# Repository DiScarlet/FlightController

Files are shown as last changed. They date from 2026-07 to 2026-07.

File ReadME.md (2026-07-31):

# Custom Flight Controller

A custom STM32F405-based flight controller designed from the ground up for modern FPV drones. Supports 4S–6S LiPo batteries, four ESC outputs with DShot, USB-C programming, and the ICM-42688-P IMU. The repository includes complete schematics, PCB design, CAD assembly, hardware documentation, and firmware flashing/bring-up guides. Designed for Betaflight compatibility with future ArduPilot support and additional onboard peripherals.

A preview of the complete assembly by Autodesk Viewer: https://autode.sk/4bVkogq

---

## Documentation

The repository contains additional documentation describing both the hardware and firmware aspects of the project.

Detailed information about the PCB architecture, power distribution, interfaces, mechanical design, manufacturing considerations, and future hardware revisions can be found in **`Docs/Hardware.md`**.

Firmware-related documentation, including programming interfaces, flashing instructions, hardware bring-up, Betaflight target information, and the planned firmware development roadmap, is available in **`Docs/Firmware.md`**.

---

## Repository Structure

FlightController/
├── CAD_Rendered/             # Fusion 360 assembly and mechanical models
├── FCHardware/               # KiCad project files
├── Devlogs/                  # The overall folder with devlog documents
│   ├── Images/                 # Figures and renders
│   └── Journal.md              # Development journal
├── Docs/                     #Documentation
│   ├── Hardware.md         
│   └── Firmware.md
├── ComponentsReferences.csv  # Component purchasing references (BOM)
├── FCHardware.csv            # Design references and documentation
└── README.md

---

## Gallery

### Schematic Overview

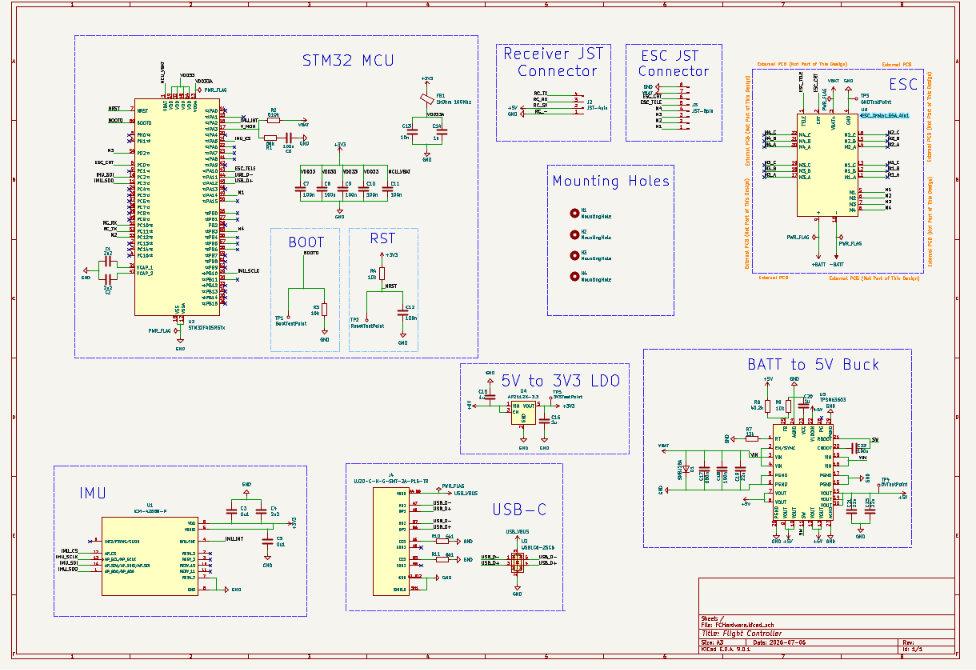
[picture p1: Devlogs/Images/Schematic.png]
Schematic


### PCB Layout (2D)

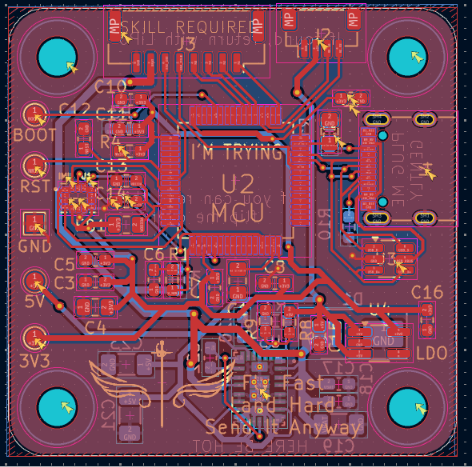
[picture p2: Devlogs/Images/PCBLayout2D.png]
PCB Layout


### PCB Front (3D)

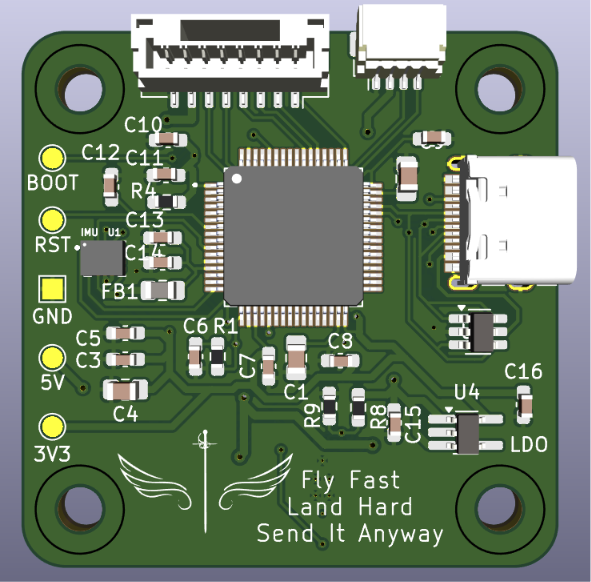
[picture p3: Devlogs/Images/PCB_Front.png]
PCB Front


### PCB Back (3D)

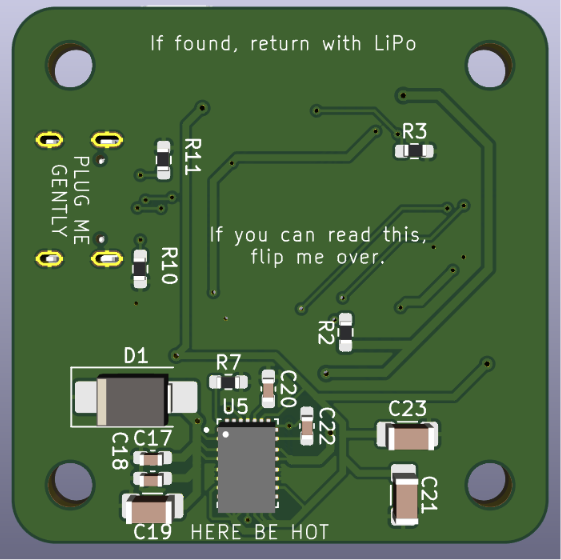
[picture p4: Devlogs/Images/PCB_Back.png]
PCB Back


### Fusion 360 Assembly

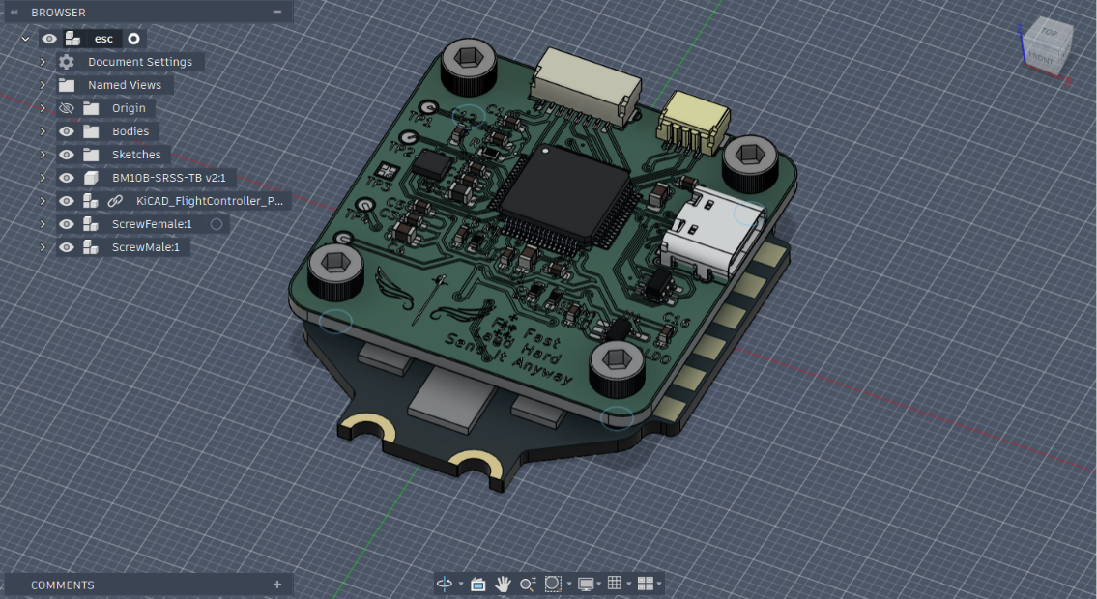
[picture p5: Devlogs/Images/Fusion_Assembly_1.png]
Fusion Assembly 1


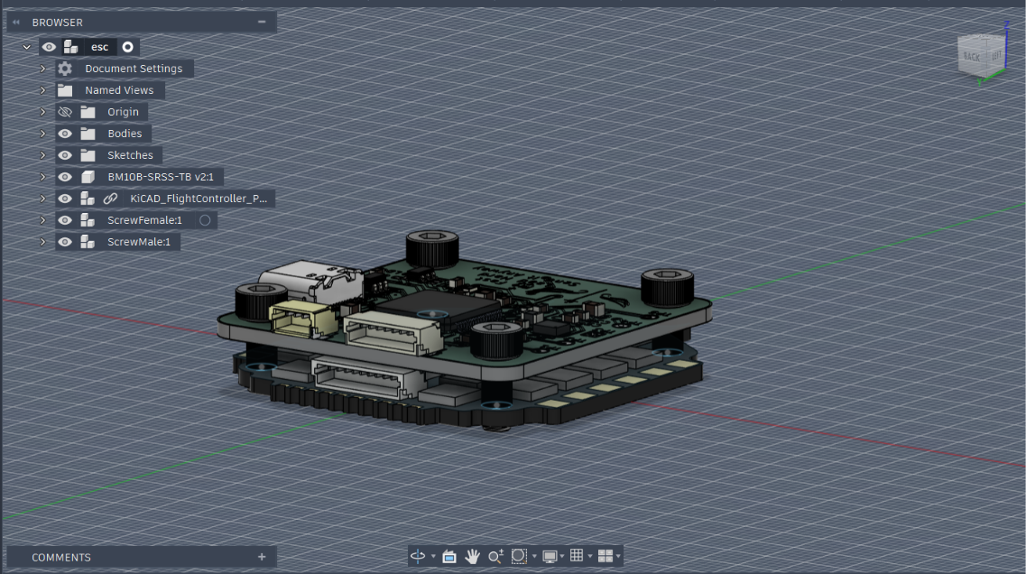
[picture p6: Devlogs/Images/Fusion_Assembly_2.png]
Fusion Assembly 2

---

## Acknowledgements

This project would not have been possible without the documentation, manuals, and resources provided by the engineering community. 

Special thanks to:
- STMicroelectronics, TDK InvenSense, Texas Instruments, Diodes Incorporated, Betaflight, Sahil Parashar for providing the generic ESC model that was adapted for this project, KiCad, Autodesk.
- **My family and friends** for their encouragement and support throughout the project.

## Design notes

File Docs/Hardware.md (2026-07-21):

# Hardware

This document describes the hardware design of the custom STM32F405-based flight controller developed throughout this project. The goal was to create a compact flight controller suitable for modern 4S–6S FPV drones while understanding every subsystem involved in the design process, from power regulation and sensor integration to PCB layout and mechanical compatibility.

The board follows the standard **30.5 × 30.5 mm mounting pattern**, allowing it to stack directly with compatible 4-in-1 ESCs such as the Hobbywing XRotor 65A used during development.

---

## Hardware Overview

The controller is built around the **STM32F405RGT6**, an ARM Cortex-M4 microcontroller widely used by the Betaflight ecosystem. Besides offering native USB support and sufficient processing power for modern flight control algorithms, choosing this MCU also makes future firmware development significantly easier due to the amount of existing documentation and community support.

Motion sensing is provided by the **ICM-42688-P** inertial measurement unit connected over SPI. Using SPI instead of I²C reduces communication latency and allows significantly higher update rates, which are essential for responsive flight control.

The board is powered directly from a **4S–6S LiPo battery**. Power conversion is performed in two stages. First, a TPSM63603 synchronous buck converter generates a regulated 5 V rail from the battery voltage. A dedicated AP2112K-3.3 low-dropout regulator then provides a clean 3.3 V supply for the microcontroller, IMU and other sensitive digital circuitry. Separating the switching regulator from the digital supply helps reduce switching noise reaching the sensors.

Battery voltage is measured using a resistor divider connected to one of the STM32 ADC inputs, while current consumption is obtained from the ESC's analog current output. These measurements allow the firmware to estimate battery state and power consumption during flight.

Communication with the ESC is performed using the DShot digital protocol, while ESC telemetry provides additional runtime information. An ExpressLRS receiver connects through UART, and additional communication interfaces have been reserved for future peripherals such as GPS, barometers or LiDAR modules.

Schematics

---

## PCB Design

The PCB was designed as a two-layer board with a continuous ground plane on both sides wherever possible. Particular attention was given to minimizing return current paths, placing decoupling capacitors close to their respective power pins and keeping high-speed SPI traces as short as practical.

USB differential pairs were routed together with matched topology, while power routing was prioritised before signal routing to ensure sufficient copper width on higher-current nets. Throughout the routing process I attempted to minimise unnecessary vias and avoided routing beneath sensitive analog circuitry whenever practical.

Rather than striving for the shortest possible traces everywhere, the layout prioritises predictable current flow, clean power distribution and component placement that follows each manufacturer's layout recommendations.

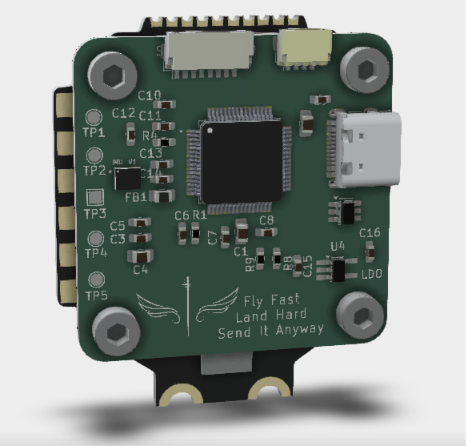
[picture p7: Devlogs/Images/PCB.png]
PCB


---

## Power Architecture

Power distribution is one of the most critical parts of the design. Since the board operates directly from a LiPo battery whose voltage changes significantly during discharge, careful regulation is required before powering the digital electronics.

The TPSM63603 generates the main 5 V rail from the battery input. This rail supplies external peripherals while also feeding the AP2112K regulator responsible for generating the clean 3.3 V supply used by the STM32, IMU and supporting circuitry.

Each power domain includes local decoupling capacitors positioned according to the manufacturers' recommendations. Ferrite bead filtering is also used to isolate particularly noise-sensitive sections of the circuit.

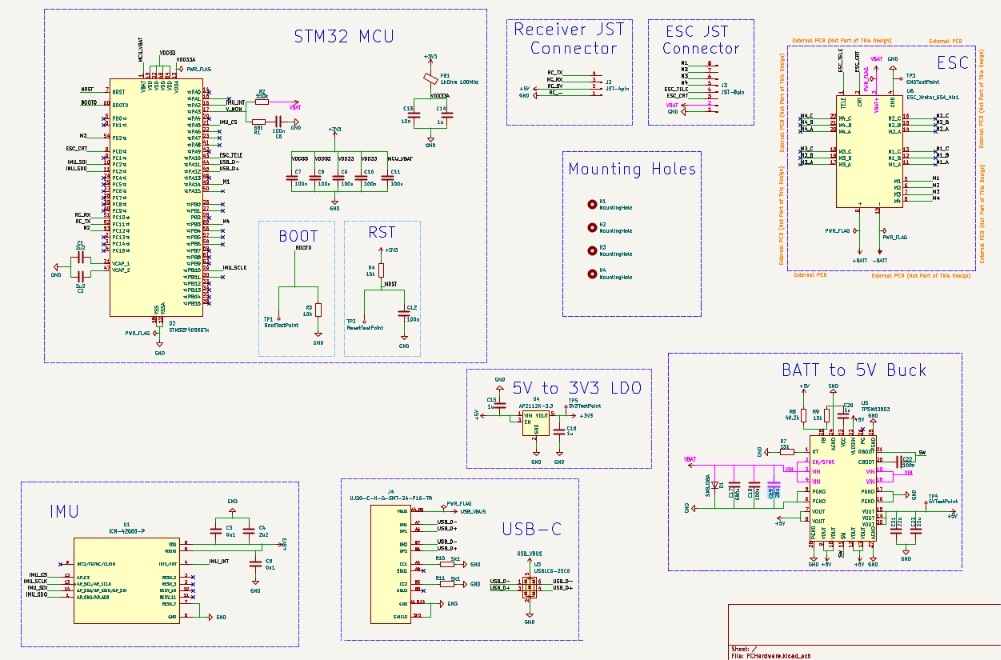
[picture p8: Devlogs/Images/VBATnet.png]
VBAT


---

## Microcontroller

The STM32F405 acts as the central controller for the entire system. It communicates with the IMU over SPI, receives radio commands through UART, generates DShot motor outputs and continuously monitors battery voltage and current through its ADC peripherals.

USB Full-Speed support allows firmware flashing and configuration without requiring an external programmer once the board has been brought up successfully.

During development, SWD remains the preferred programming interface because it provides full debugging capabilities and recovery if the firmware becomes corrupted.

PCB 3D

---

## IMU

Orientation of the ICM-42688-P follows the manufacturer's recommended reference frame to simplify firmware configuration. Special attention was given to local power decoupling and short SPI routing in order to reduce supply noise and communication latency.

The IMU communicates with the STM32 through dedicated SPI lines together with an interrupt line used for high-frequency sensor updates.

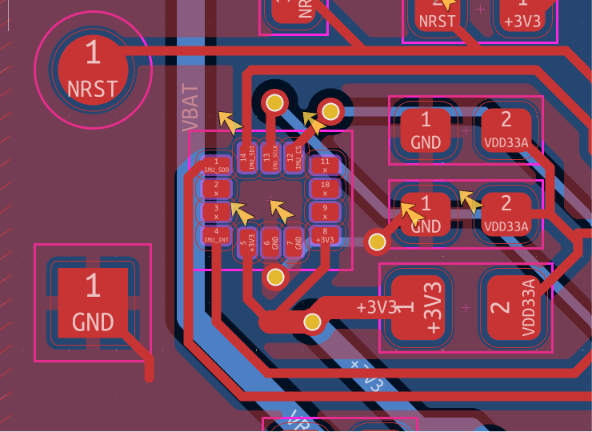
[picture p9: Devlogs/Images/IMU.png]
IMU


---

## External Interfaces

The board exposes several interfaces required by a modern flight controller.

A USB Type-C connector provides firmware flashing and configuration together with integrated ESD protection. Programming and debugging are additionally supported through dedicated SWD test pads.

Motor control is performed through DShot outputs connected to the ESC, while ESC telemetry and analog current sensing return runtime information back to the STM32.

An ExpressLRS receiver connects through UART, and additional interfaces remain available for future expansion.

---

## Test Points

Instead of dedicating valuable PCB space to buttons and programming headers, several functions are exposed through SMD test pads.

The board includes accessible test points for:

- 3.3 V
- 5 V
- Ground
- BOOT0
- NRST
- SWD programming

These pads simplify firmware flashing, debugging and hardware validation while keeping the PCB compact.

---

## Revision 2 Ideas

The most significant changes would include improving the routing around the buck converter, refining connector placement to simplify assembly, integrating more cleanly with the ESC stack, and exposing additional communication interfaces for peripherals such as GPS and LiDAR. Hardware validation of the first manufactured revision will ultimately determine which of these changes provide the greatest benefit.

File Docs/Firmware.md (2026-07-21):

# Firmware

The hardware has been designed primarily for Betaflight running on the STM32F405RGT6 microcontroller. Although the PCB has not yet been manufactured, the firmware workflow has already been planned to simplify the bring-up process once the first revision of the board arrives.

The STM32 provides two programming interfaces. During development I intend to use the SWD interface together with an ST-Link programmer, as it allows full debugging and recovery even if the firmware becomes corrupted. For normal firmware updates, the USB Type-C connector can be used through the STM32 built-in DFU bootloader.

---

## Programming Interfaces

The board exposes two independent programming methods.

### SWD

The SWD interface is available through dedicated test pads exposing:

- SWDIO
- SWCLK
- NRST
- 3.3 V
- GND

This interface will be used for the initial bring-up of the board, firmware development and debugging.

PCB 

---

### USB DFU

The STM32F405 contains a factory bootloader stored in ROM. By pulling **BOOT0** high during reset, the MCU enters Device Firmware Upgrade (DFU) mode and can be programmed directly over the USB Type-C connector without requiring an external programmer.

Both **BOOT0** and **NRST** are exposed as SMD test pads instead of push buttons in order to reduce PCB size.

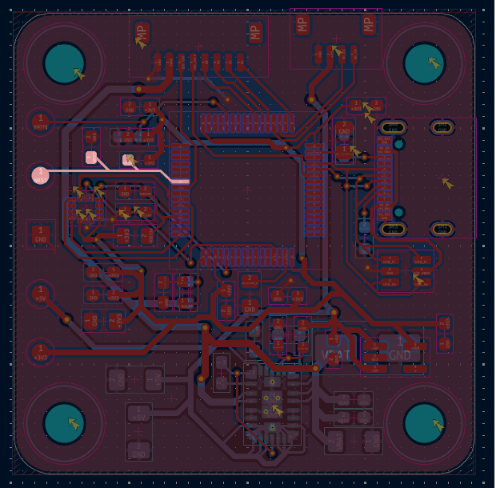
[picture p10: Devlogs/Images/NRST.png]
NRST


---

## First Power-Up

Once the PCB is assembled, the first goal is simply to verify that the hardware behaves as expected before any flight firmware is installed.

The planned validation sequence is:

1. Verify that there are no shorts on the power rails.
2. Apply power from a current-limited bench supply.
3. Confirm that the 5 V rail is generated correctly.
4. Verify the 3.3 V regulator output.
5. Ensure that the STM32 starts correctly.
6. Test USB enumeration.
7. Verify SWD communication.
8. Confirm SPI communication with the IMU.
9. Validate battery voltage and current sensing.

Only after these checks pass will Betaflight be flashed.

---

## Betaflight

The hardware was designed around the STM32F405 specifically because it is well supported by Betaflight.

Once the board has been electrically validated, the next milestone will be creating a custom Betaflight target describing the hardware configuration, including the IMU, motor outputs, UART assignments and ADC channels.

After the target is complete, the board should be configurable directly through Betaflight Configurator.

Link: https://betaflight.com/
Configurator: https://app.betaflight.com/

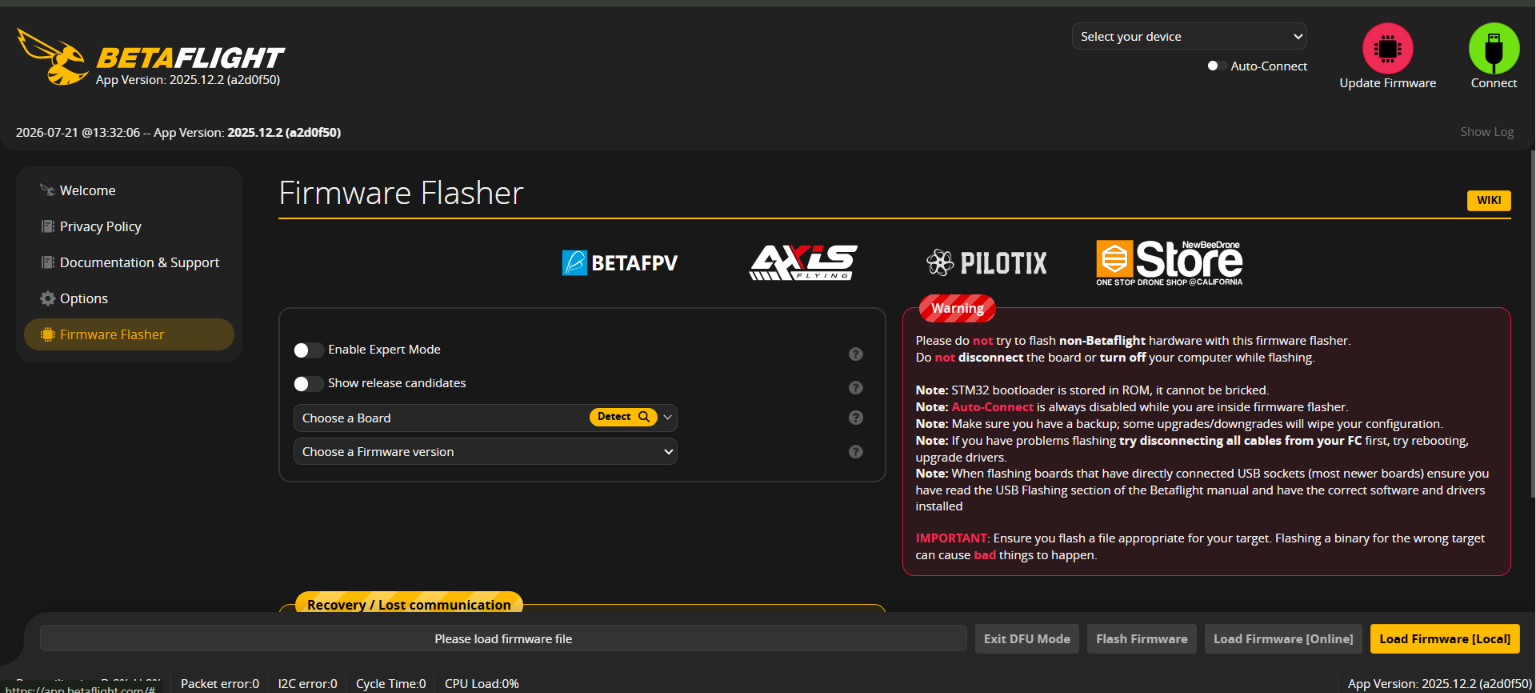
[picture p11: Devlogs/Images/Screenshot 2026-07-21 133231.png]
Betaflight


---

## Future Development

The first revision focuses entirely on reliable flight control hardware. Once basic functionality has been verified, future firmware development will expand to include additional peripherals such as GPS, LiDAR, barometer support and, eventually, ArduPilot compatibility.

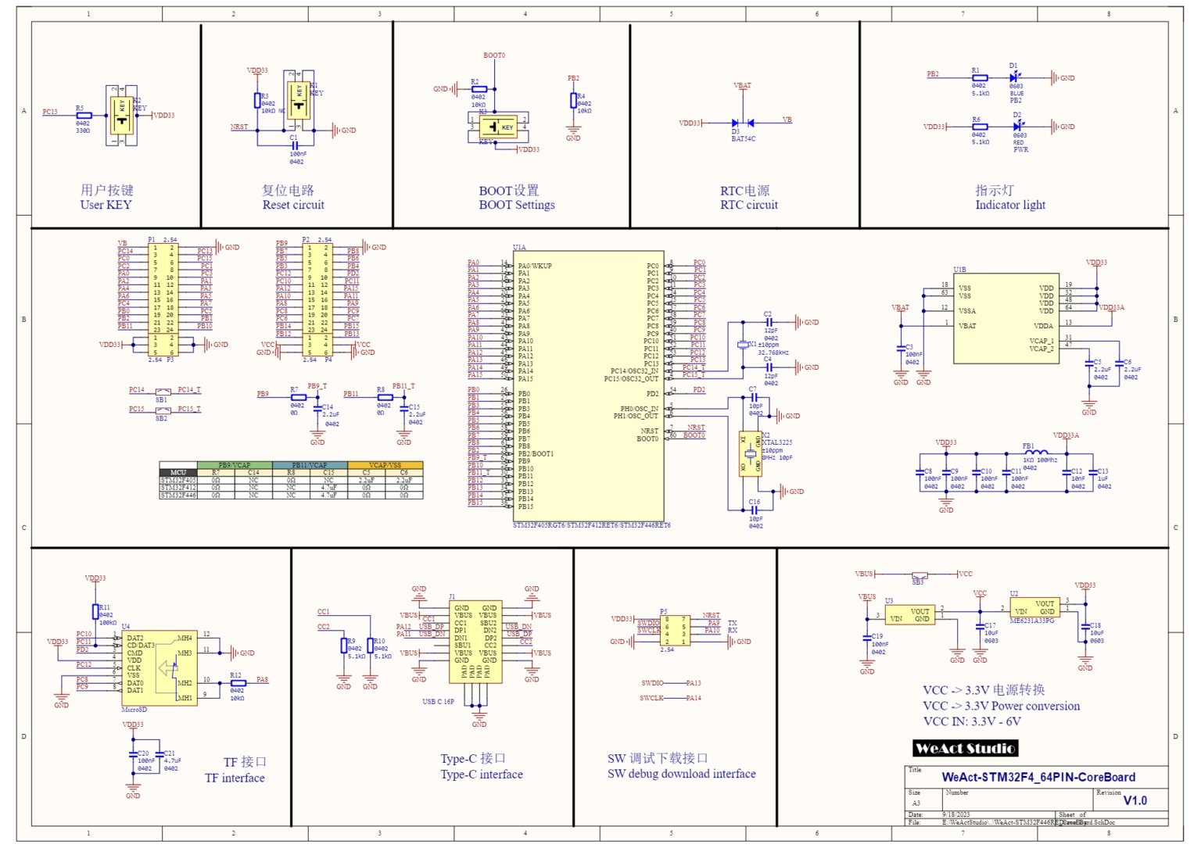
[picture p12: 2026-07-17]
FCHardware/Images/STM32F405-Development-Board-Schematic-1536x1085.jpg

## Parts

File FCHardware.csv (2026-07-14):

Reference | Value | Footprint | Datasheet | Qty | DNP | Exclude from BOM | Exclude from Board
C7,C12 | 1u | Capacitor_SMD:C_0603_1608Metric_Pad1.08x0.95mm_HandSolder | ~ | 2
C8,C11,C13,C22,C23,C25 | 100n | Capacitor_SMD:C_0603_1608Metric_Pad1.08x0.95mm_HandSolder | ~ | 6
C9 | 2n2 | Capacitor_SMD:C_0603_1608Metric_Pad1.08x0.95mm_HandSolder | ~ | 1
C10 | 680n | Capacitor_SMD:C_1210_3225Metric_Pad1.33x2.70mm_HandSolder | ~ | 1
C15,C16 | 22u | Capacitor_SMD:C_1206_3216Metric_Pad1.33x1.80mm_HandSolder | ~ | 2
C24 | 10u | Capacitor_SMD:C_0805_2012Metric_Pad1.18x1.45mm_HandSolder | ~ | 1
D1 | SMBJ28A | Diode_SMD:D_SMB_Handsoldering | ~ | 1
H1,H2,H3,H4 | MountingHole | MountingHole:MountingHole_3.2mm_M3 | ~ | 4 |  | Excluded from BOM
J1 | JST-8pin | Connector_JST:JST_GH_SM08B-GHS-TB_1x08-1MP_P1.25mm_Horizontal | ~ | 1
J3 | USB_C_Receptacle_USB2.0_16P |  | https://www.usb.org/sites/default/files/documents/usb_type-c.zip | 1
R7,R8 | 2k2 | Resistor_SMD:R_0603_1608Metric_Pad0.98x0.95mm_HandSolder | ~ | 2
R11 | 27.4k | Resistor_SMD:R_0603_1608Metric_Pad0.98x0.95mm_HandSolder | ~ | 1
R12 | 23.2k | Resistor_SMD:R_0603_1608Metric_Pad0.98x0.95mm_HandSolder | ~ | 1
R13,R24,R27 | 10k | Resistor_SMD:R_0603_1608Metric_Pad0.98x0.95mm_HandSolder | ~ | 3
R22 | 510k | Resistor_SMD:R_0603_1608Metric_Pad0.98x0.95mm_HandSolder | ~ | 1
R23 | 68k | Resistor_SMD:R_0603_1608Metric_Pad0.98x0.95mm_HandSolder | ~ | 1
R28,R29 | 5k1 +-5% | Resistor_SMD:R_0603_1608Metric_Pad0.98x0.95mm_HandSolder | ~ | 2
SW3 | SW_Push |  | ~ | 1
TP2 | GNDTestPoint |  | ~ | 1
TP3 | 3V3TestPoint |  | ~ | 1
TP5 | ENTestPoint |  | ~ | 1
U2 | MPU-6050 | Sensor_Motion:InvenSense_QFN-24_4x4mm_P0.5mm | https://invensense.tdk.com/wp-content/uploads/2015/02/MPU-6000-Datasheet1.pdf | 1
U4 | TPSM63603 | TPSM63603EXTRDHR | https://www.ti.com/lit/ds/symlink/tpsm63603.pdf | 1
U5 | ESC_Xrotor_65A_4in1 |  | https://www.hobbywing.com/en/uploads/file/20250324/715cf619a357b18a11761e3bb13e4f6d.pdf | 1
U8 | ESP32-S3-MINI-1U | RF_Module:ESP32-S2-MINI-1U | https://www.espressif.com/sites/default/files/documentation/esp32-s3-mini-1_mini-1u_datasheet_en.pdf | 1
U9 | USBLC6-2SC6 | Package_TO_SOT_SMD:SOT-23-6 | https://www.st.com/resource/en/datasheet/usblc6-2.pdf | 1

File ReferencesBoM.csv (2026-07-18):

Reference | Value | Store Name | Link
C1,C2,C4 | 2u2 | 0805YC225JAT2A | https://www.mouser.fi/en/ProductDetail/KYOCERA-AVX/0805YC225JAT2A?qs=%252BdQmOuGyFcHAs%2FdSKfbQcg%3D%3D
C3,C5 | 0u1 | 0603YA102FAT2A | https://www.mouser.fi/en/ProductDetail/KYOCERA-AVX/0603YA102FAT2A?qs=Q0wCMCRSJ1vE1Ym6h4QWAA%3D%3D
C13 | 10n | KAF15AR72A103JM | https://www.mouser.fi/en/ProductDetail/KYOCERA-AVX/KAF15AR72A103JM?qs=Jm2GQyTW%2FbiSEofrKTFSYg%3D%3D
C14,C20,C15,C16 | 1u | KGM15BR71C105JT | https://www.mouser.fi/en/ProductDetail/KYOCERA-AVX/KGM15BR71C105JT?qs=Z%252BL2brAPG1K2MbrAaZa7Nw%3D%3D
C7,C8,C9,C10,C11,C12,C6,C18,C22 | 100n | KGF15AR71H104JT | https://www.mouser.fi/en/ProductDetail/KYOCERA-AVX/KGF15AR71H104JT
C9 | 2n2 | KAF15AR71H222KT | https://www.mouser.fi/en/ProductDetail/KYOCERA-AVX/KAF15AR71H222KT?qs=OcgtsXO%252B3gvSeuEwjFHfGw%3D%3D
C10 | 680n | 06035C682MAT2A | https://www.mouser.fi/en/ProductDetail/KYOCERA-AVX/06035C682MAT2A
C19,C21,C23 | 22u | C3216X5R1V226M160AC | https://www.mouser.fi/en/ProductDetail/TDK/C3216X5R1V226M160AC?qs=NRhsANhppD8TwN31eZ1xGQ%3D%3D
C24 | 10u | MCASL21GBB7106KTNA01 | https://www.mouser.fi/en/ProductDetail/TAIYO-YUDEN/MCASL21GBB7106KTNA01
D1 | SMBJ28A | SMBJ28A | https://www.mouser.fi/en/ProductDetail/Taiwan-Semiconductor/SMBJ28A?qs=tHU%2FlV7kTyQeXZsIvFkTlA%3D%3D
FB1 | 1kOhm 100Mhz | ABPY00201209102Y00 | https://www.mouser.fi/en/ProductDetail/Pulse-Electronics/ABPY00201209102Y00?qs=DRkmTr78QAQV9rs2r0z4%2Fg%3D%3D
H1,H2,H3,H4 | MountingHole | M3 kuusiokoloruuvi 18mm | https://kauppa.sintosen.com/product/1973/m3-kuusiokoloruuvi-a2-70-teras-10kplpss-iso7380
J1 | JST-8pin | Cable JST GH 1 | 25mm 8pin 150 mm | https://kauppa.sintosen.com/product/3806/jst-gh-125-liitin-naaras-johdolla
J1 | JST-8pin-Connector | 502386-0870 | https://www.mouser.fi/en/ProductDetail/Molex/502386-0870?qs=Fn3VdHBzkclKyntjDrqNyw%3D%3D
J2 | JST-4pin
J3 | USB_C_Receptacle_USB2.0_16P | UJ20-C-H-G-SMT-2A-P16-TR | https://www.mouser.fi/en/ProductDetail/Same-Sky/UJ20-C-H-G-SMT-2A-P16-TR?qs=6avfeC6zeS4lRZlgHZHlwQ%3D%3D
R7,R8 | 2k2 | RN73R1JTTD2201B50 | https://www.mouser.fi/en/ProductDetail/KOA-Speer/RN73R1JTTD2201B50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
R11 | 27.4k | RC0603FR-0727K4L | https://www.mouser.fi/en/ProductDetail/YAGEO/RC0603FR-0727K4L?qs=diQw95jMAeON0J0BtxrSNg%3D%3D
R12 | 23.2k | RC0603FR-0723K2L | https://www.mouser.fi/en/ProductDetail/YAGEO/RC0603FR-0723K2L?qs=diQw95jMAePwAyVFAaRAcQ%3D%3D
R13,R24,R27 | 10k | RC0603FR-0710KL | https://www.mouser.fi/en/ProductDetail/YAGEO/RC0603FR-0710KL?qs=grNVn54RoB%252B3GtjbJj3wJQ%3D%3D
R2 | 510k | RC0603FR-07510KL | https://www.mouser.fi/en/ProductDetail/YAGEO/RC0603FR-07510KL?qs=gt6vzsuosg24q32x%252BBO%252BsA%3D%3D
R7 | 13k | ERA-3ARW133V | https://www.mouser.fi/en/ProductDetail/Panasonic/ERA-3ARW133V
R8 | 40.2k | TNPW060340K2BETA | https://www.mouser.fi/en/ProductDetail/Vishay/TNPW060340K2BETA
R1 | 68k | RC0603FR-1368KL | https://www.mouser.fi/en/ProductDetail/YAGEO/RC0603FR-1368KL?qs=IuGqVx9wL0JGAH4a3IMPOw%3D%3D
R28,R29 | 5k1 | RC0603FR-075K1L | https://www.mouser.fi/en/ProductDetail/YAGEO/RC0603FR-075K1L?qs=gt6vzsuosg2jUUwxnI2PJQ%3D%3D
U1 | ICM-42688-P | ICM-42688-P | https://www.mouser.fi/en/ProductDetail/TDK-InvenSense/ICM-42688-P?qs=OlC7AqGiEDk8QrNAV728zw%3D%3D
U2 | STM32F405RGTx | STM32F405RGT6 | https://www.mouser.fi/en/ProductDetail/STMicroelectronics/STM32F405RGT6?qs=Z8%252BeY1k3TIKgj7QWsYGpQw%3D%3D
U3 | USBLC6-2SC6 | USBLC6-2SC6 | https://www.mouser.fi/en/ProductDetail/STMicroelectronics/USBLC6-2SC6?qs=po45yt2pPpu%2FhNIlwQdTlg%3D%3D
U4 | AP2112K-3.3 | AP2112K-3.3TRG1 | https://www.mouser.fi/en/ProductDetail/Diodes-Incorporated/AP2112K-3.3TRG1?qs=x6A8l6qLYDDPYHosCdzh%2FA%3D%3D
U5 | TPSM63603 | TPSM63603SRDHR | https://www.mouser.fi/en/ProductDetail/Texas-Instruments/TPSM63603SRDHR?qs=tlsG%2FOw5FFhaJm%252BTRcoafA%3D%3D
ESC/U6 | ESC_Xrotor_65A_4in1 | Hobbywing XRotor 65A FPV 4in1 ESC 30902064 | https://hobbyfactory.fi/et/p87240/hobbywing-xrotor-65a-fpv-4in1-esc-30902064
RECEIVER.Radiomaster XR1 Nano Multi-Frequency ExpressLRS Receiver EU-LBT | https://originhobbies.com/shop/radio-control/radio-receivers/elrs-protocol/radiomaster-xr1-nano-multi-frequency-expresslrs-receiver-eu-lbt/

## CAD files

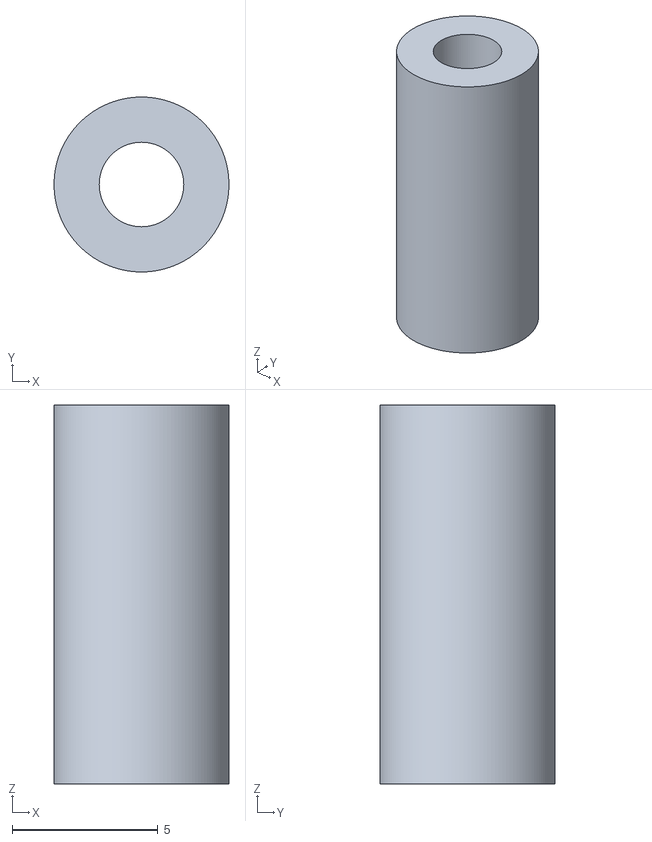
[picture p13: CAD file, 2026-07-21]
CAD_Rendered/Components/Screw/13mm.stl
6.00 x 6.00 x 13.0

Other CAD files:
CAD_Rendered/FC_ESC_Assembly.step
CAD_Rendered/Components/KiCAD_FlightController_PCB.step
FCHardware/KiCAD_Libs/FC3DModels/JST_SH_SM08B-SRSS-TB_1x08-1MP_P1.00mm_Horizontal.step
FCHardware/KiCAD_Libs/FC3DModels/ICM-42688-P.step
FCHardware/KiCAD_Libs/FC3DModels/TPSM63603EXTRDHR.step
FCHardware/KiCAD_Libs/FC3DModels/STM32F405RGT6.STEP
FCHardware/KiCAD_Libs/FC3DModels/UJ20-C-H-G-SMT-2A-P16-TR.step
FCHardware/KiCAD_Libs/FC3DModels/PRT-14417--3DModel-STEP-1.STEP
CAD_Rendered/Components/Screw/CHC M3 L8.step
CAD_Rendered/FC_ESC_Assembly.3mf

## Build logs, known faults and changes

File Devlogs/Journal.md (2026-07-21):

title: "Flight Controller"
author: "Diana"
description: "Design and development of a custom STM32F405-based flight controller for Betaflight-compatible FPV drones"
created_at: "2026-07-06"

----------------------
## Project Journal

### Day 1
created_at: "2026-07-06"

Lapse Links: 
- [Lapse Schematics 1](https://lapse.hackclub.com/timelapse/7EcZ5cB8u3wI)
- [Lapse Schematics 2](https://lapse.hackclub.com/timelapse/V2QrQ_YrS28b)
Day 1: I am really excited to start this amazing project! 
I'll put a lot of work into this. I looked up some tutorials already, but a lot of them are too old and don't use modern technology or they use components I'd prefer not to.I want to start by following the schematics in the tutorial, and then, once I understand the full idea, switch to a completely different version created entirely by me.
I added the initial component schematics with the ESP32 WROOM Module. I might change it later, but it is currently missing a lot of components, so the tutorial has to add them and wire them up. This will help me better understand the internal structure of the ESP32 WROOM module. Even if I switch to more modern microcontrollers later, it will still help me progress faster because I will understand the internal wiring.
So, here is the basic structure of all the components that I've added and wired:
1) Microcontroller: I decided to go with the ESP32 WROOM 32.
2) CP2104: For USB-to-UART communication.
3) Flashing Sequence: For automatic firmware updates.
4) USB-B / USB-C: I will decide on one later. 
5) Motor Connectors: For connecting to the motors.
6) H-Bridge Circuit: For controlling the motors.
7) 3V3 Voltage Regulator: For stabilizing the input voltage to the ESP32.
8) Battery Charger: To prevent damage to the battery.
9) Accelerometer (MPU6050): This also contains a gyroscope, a temperature sensor, and a Digital Motion Processor that act as sensors for the controller's brain.
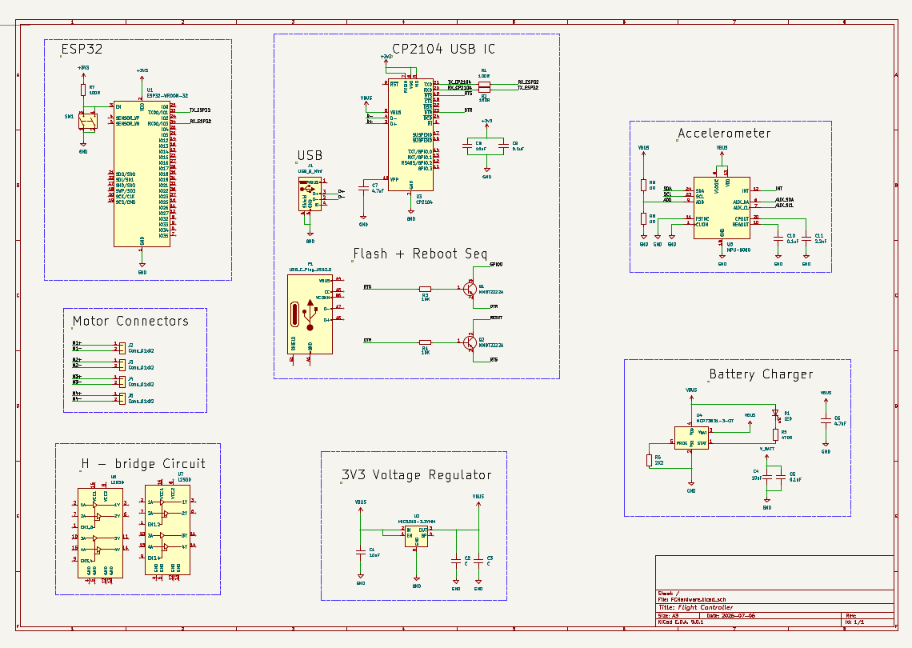
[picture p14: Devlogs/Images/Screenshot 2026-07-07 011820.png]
Schematics Day 1

This is going to be an epic project, and I am really excited to begin. I am still not sure if this is the right controller to choose, but many tutorials suggest it, so who am I to go against them?
I like what I've done so far. Even though I am still not finished, I understand way more now by looking at tutorials and doing my own thing. I'll try to optimize it tomorrow.

---------------------
created_at: "2026-07-07"

Lapse Links: 
- [Lapse Schematics 3](https://lapse.hackclub.com/timelapse/JKiI6UassHQw)
### Day 2
Even though I really enjoyed the progress of working on a lot of interesting stuff yesterday, there were too many unnecessary components. I changed the main controller to the Adafruit ESP32 Feather V2, which reduced the amount of components drastically.
This board has a lot of components already integrated into its internal structure, so I could alter the following elements:
1) Microcontroller: Adafruit ESP32 Feather V2. Why V2? It has USB-C and easier power management already integrated.
2) Removed CP2104: Already integrated into item 1. 
3) Removed Flashing Sequence: Already integrated into item 1.
4) Removed USB-B / USB-C: Already integrated into item 1.
5) H-Bridge Circuit: Upgraded to more modern DRV8833PWP drivers.
6) Removed 3V3 Voltage Regulator: Already integrated into item 1. 
7) Removed Battery Charger: Already integrated into item 1. 

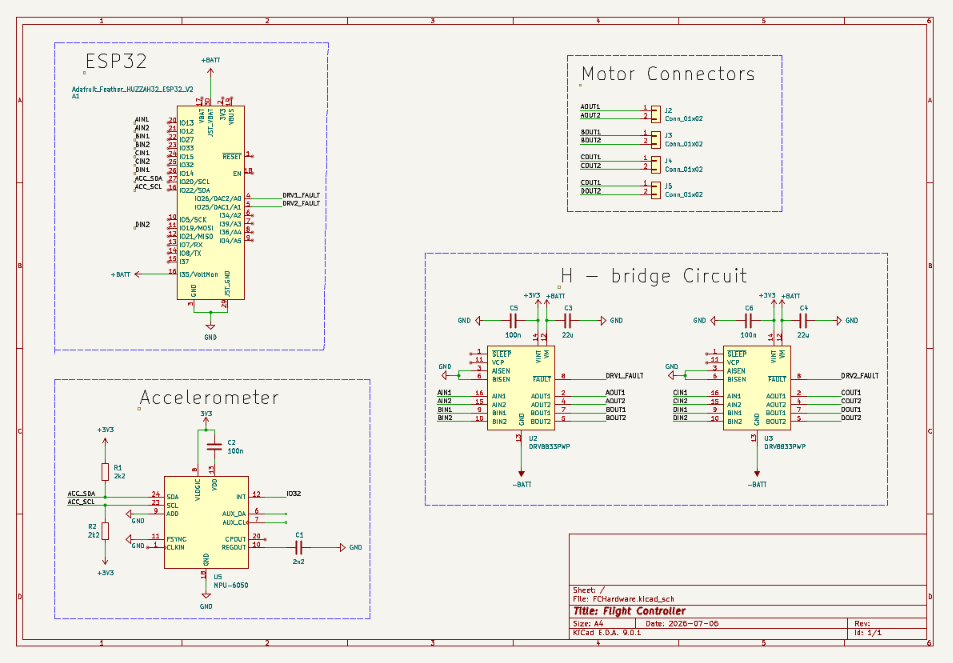
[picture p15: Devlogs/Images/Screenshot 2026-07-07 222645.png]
Schematics Day 2

Overall, the schematics look way more readable now, and the component switch was well worth the trouble. It did not take me that long, but it will definitely make assembly way easier.

--------------------
created_at: "2026-07-08"
Lapse Links: 
- [Lapse Schematics 4](https://lapse.hackclub.com/timelapse/zhmaA2kOq_Py)
### Day 3
To use more powerful motors, my infrastructure allows me to switch from a 1S to a 2S LiPo battery. This is mainly due to the DRV8833PWP drivers, which accept 2.7V to 10.8V — a span that falls right into the 2S range. To make this work, I chose the TPS62125DSG step-down regulator. I was wondering how to connect the battery to the PCB itself and settled on the Amass XT60PW male PCB-mount connector. Most JST connectors are too weak, and an XT90 is overkill. I ended up a bit confused by all the different power inputs and outputs, but I eventually figured out the wiring and ended up with the following schematic:
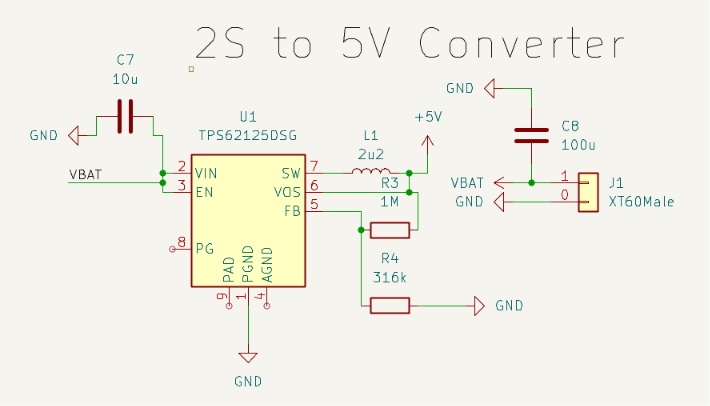
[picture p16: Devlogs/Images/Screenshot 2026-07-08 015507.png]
TPS62125DSG Wiring

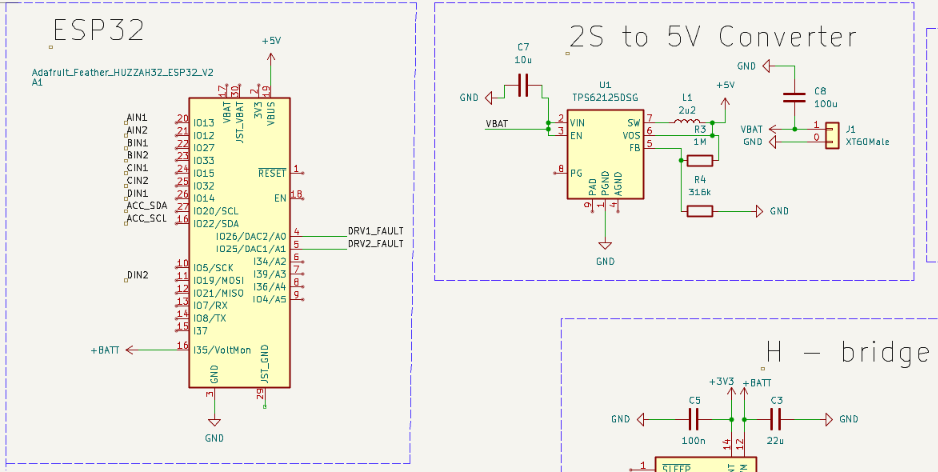
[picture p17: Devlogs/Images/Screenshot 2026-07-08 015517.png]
ESP32 + Power Schematics


--------------------
created_at: "2026-07-11"
Lapse Links: 
- [Lapse Schematics 5](https://lapse.hackclub.com/timelapse/zi6OlWzVVC0I)
### Day 4
Today I made significant modifications to the flight controller design. I stepped up from a simple 2S brushed drone concept to the prototype architecture of a real 4S 7" brushless drone.

1. Updated the buck converter

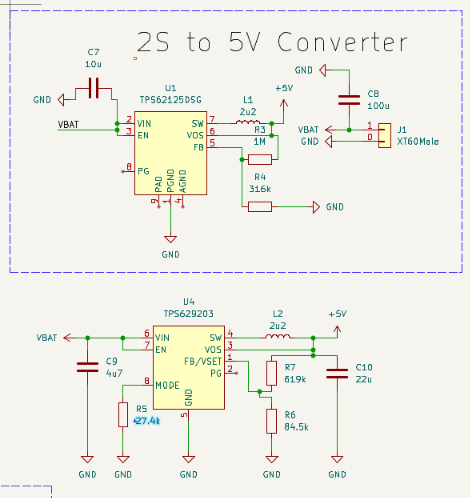
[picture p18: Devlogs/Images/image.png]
TPS629203
I replaced the TPS62125 with the newer TPS629203, which supports my new power requirements and offers better efficiency. 

2. Switched from brushed to brushless architecture

Initially, I considered replacing the DRV8833PWP because it is obsolete with the DRV8847PWPR. However, since I had to redesign the motor-driving stage anyway, I decided it made more sense to switch to brushless motors and use a dedicated 4-in-1 ESC instead of H-bridges.

Because the TPS629203 supports a 4S LiPo, I also upgraded the battery from 2S to 4S. This removed the need for additional power circuitry changes and resulted in a much cleaner flight controller schematic.

3. Selected the propulsion system

To avoid designing around unknown components, I chose the motors first and built the rest of the system around them.

Motor: Hobbywing XRotor 2807 1300KV

Product:
https://hobbywinguav.com/product/2807/

Datasheet:
https://www.hobbywing.com/uploads/file/20250207/46cccf132a1b9971633a272da27fb76f.pdf

4. Selected the ESC

Since I switched to brushless motors, I removed the H-bridge motor drivers and replaced them with a 4-in-1 ESC.

After comparing several candidates and checking compatibility with the selected motors, I chose the:

Hobbywing XRotor 65A 4-in-1 Lite BLS V2 ESC

Datasheet:
https://www.hobbywing.com/en/uploads/file/20251120/81969c41227e3db78d441e9c20476cf1.pdf

Product:
https://www.drone-fpv-racer.com/en/hobbywing-65a-4in1-6s-lite-bls-v2-fpv-esc-15678.html
[BLS Version](<Images/Screenshot 2026-07-11 032116.png>)

5. Updated motor connections

I initially changed the motor connectors to 3-pin connectors for brushless motors.

Later, I realised that since the motors connect directly to the ESC, the flight controller PCB does not need motor connectors. Therefore, I removed them from the schematic.

6. Added battery monitoring

I added:

Battery voltage monitoring using a resistor divider connected to an ESP32 ADC pin.
Battery current monitoring using the ESC's analog current output connected to another ESP32 ADC pin.
ESC telemetry connected to a UART RX pin on the ESP32.

7. Updated the power architecture

The battery is now connected directly to the ESC through an XT60 connector.

I also added:

a 680 µF bulk capacitor (provided with the ESC),
a TVS diode across VBAT and GND for transient protection.

TODO:
- Replace the ESP32 Feather development board with a custom ESP32 circuit in the final design.
- Verify the ESC telemetry connector (SH1.0) and determine the best way to interface it with my PCB.
- Verify that the ESC current output is 3.3 V compatible before connecting it directly to the ESP32 ADC.
- Run KiCad ERC and begin PCB layout.

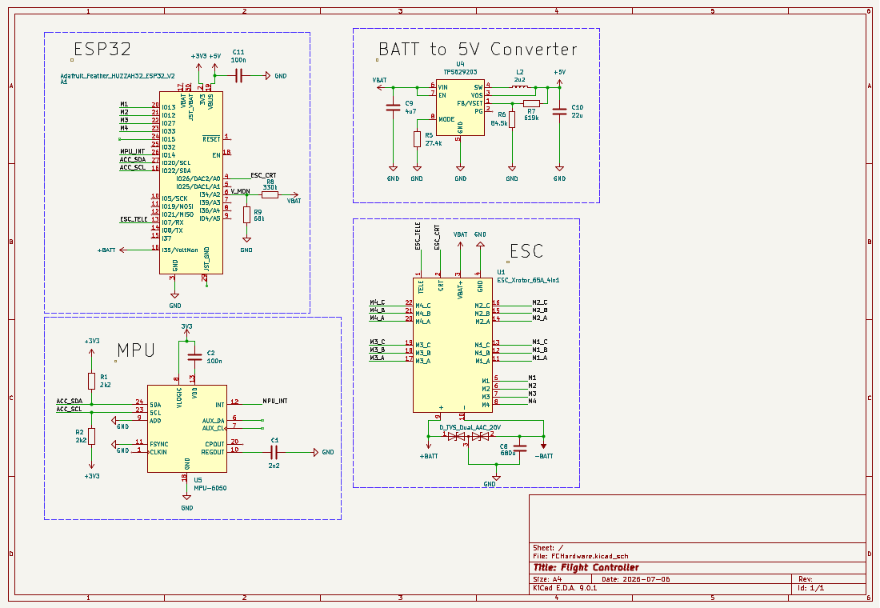
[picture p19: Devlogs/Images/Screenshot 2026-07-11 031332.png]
Full Shcematics of Today


--------------------
created_at: "2026-07-12"
Lapse Links: 
- [Lapse Schematics 6](https://lapse.hackclub.com/timelapse/6Uwn8jtsZGfW)
- [Lapse Schematics 7](https://lapse.hackclub.com/timelapse/CSfY-yu12VB2)
- [Lapse Schematics 8](https://lapse.hackclub.com/timelapse/6Uwn8jtsZGfW)
- [Lapse Schematics 9](https://lapse.hackclub.com/timelapse/6Uwn8jtsZGfW)
### Day 5
Today I replaced the ESP32 Feather V2 development board with the actual ESP32-S3-WROOM-1U module and all of the supporting circuitry required for a production PCB. The Feather dev board served me well for prototyping, but it was time to move to a real hardware design.
ESP32
- Removed the Adafruit ESP32 Feather V2 development board.
- Switched to the ESP32-S3-WROOM-1U module.
- Added the required support circuitry:
  - EN reset circuit
  - BOOT button
  - USB-C connector
  - USB D+ / D− wiring
  - Decoupling capacitors
  - Voltage divider for battery monitoring

ESP32-S3-WROOM-1U datasheet:
https://documentation.espressif.com/esp32-s3-wroom-1_wroom-1u_datasheet_en.pdf
Originally the design targeted a 4S battery:

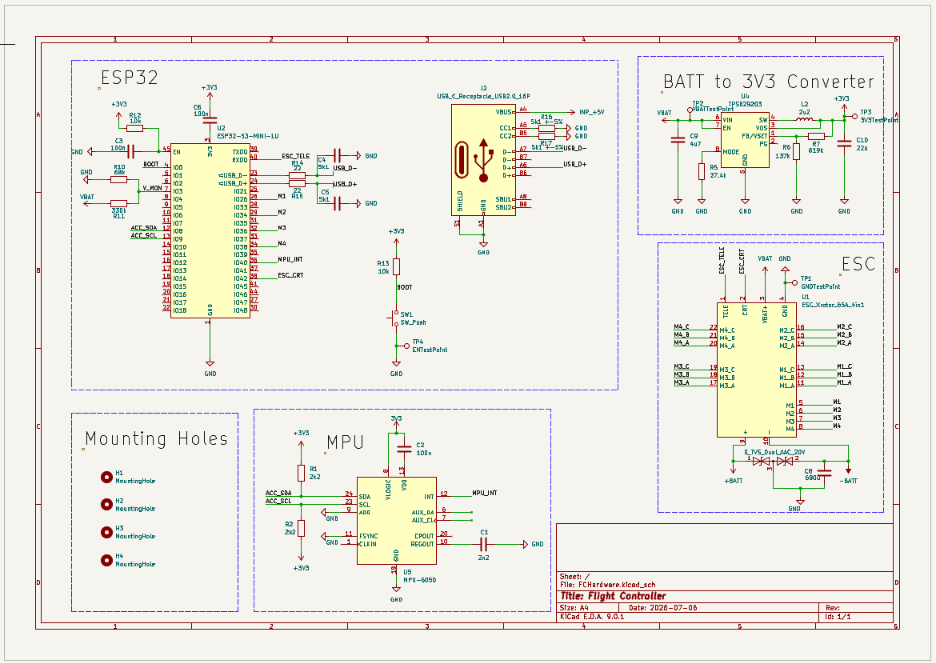
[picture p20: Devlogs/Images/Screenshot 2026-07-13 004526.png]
4S Architecture


I added:
- test points for debugging,
- PCB mounting holes,
- improved power distribution.

I then decided to redesign the power supply so the flight controller can support both **4S and 6S LiPo batteries**.

The previous TPS629203 regulator was replaced with the **TPSM63603**, which supports input voltages up to 36 V.

TPSM63603 datasheet:
https://www.ti.com/lit/ds/symlink/tpsm63603.pdf

I created a custom KiCad symbol for the TPSM63603:

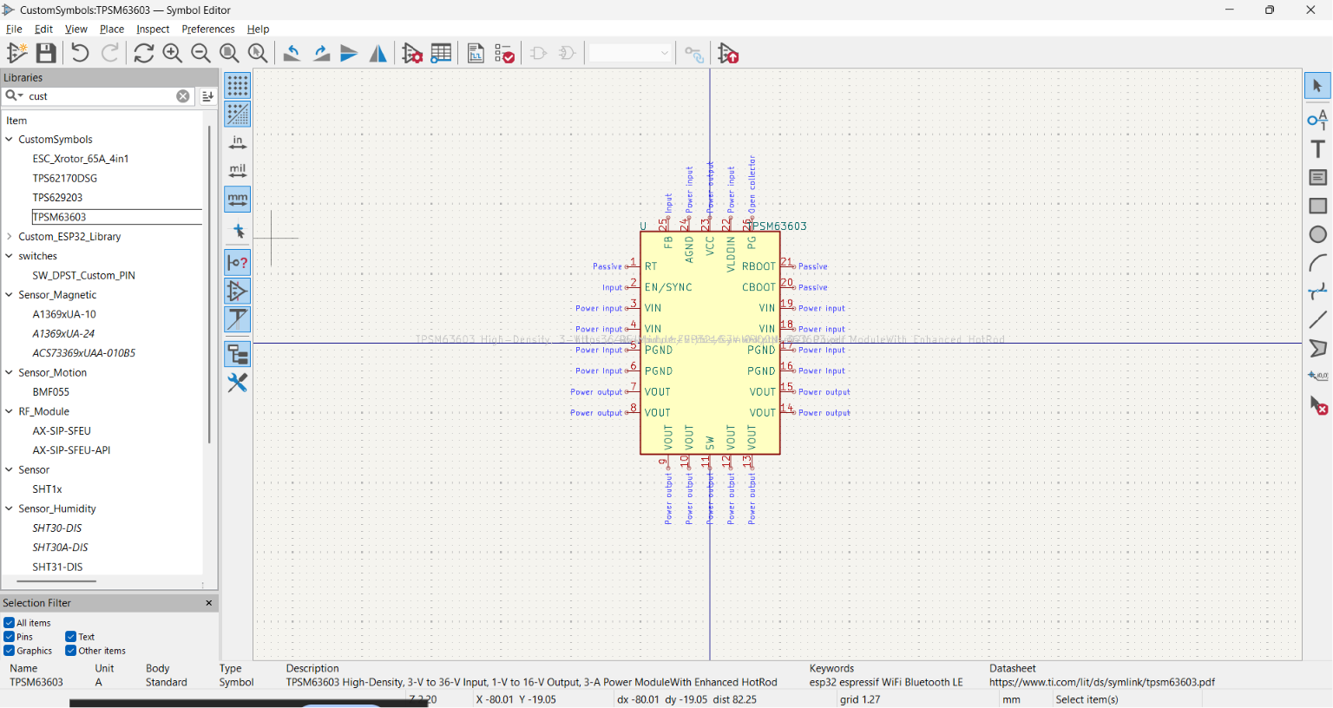
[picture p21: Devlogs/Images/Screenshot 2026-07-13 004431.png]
TPSM63603 Symbol


Then I integrated and wired the new regulator into the schematic:

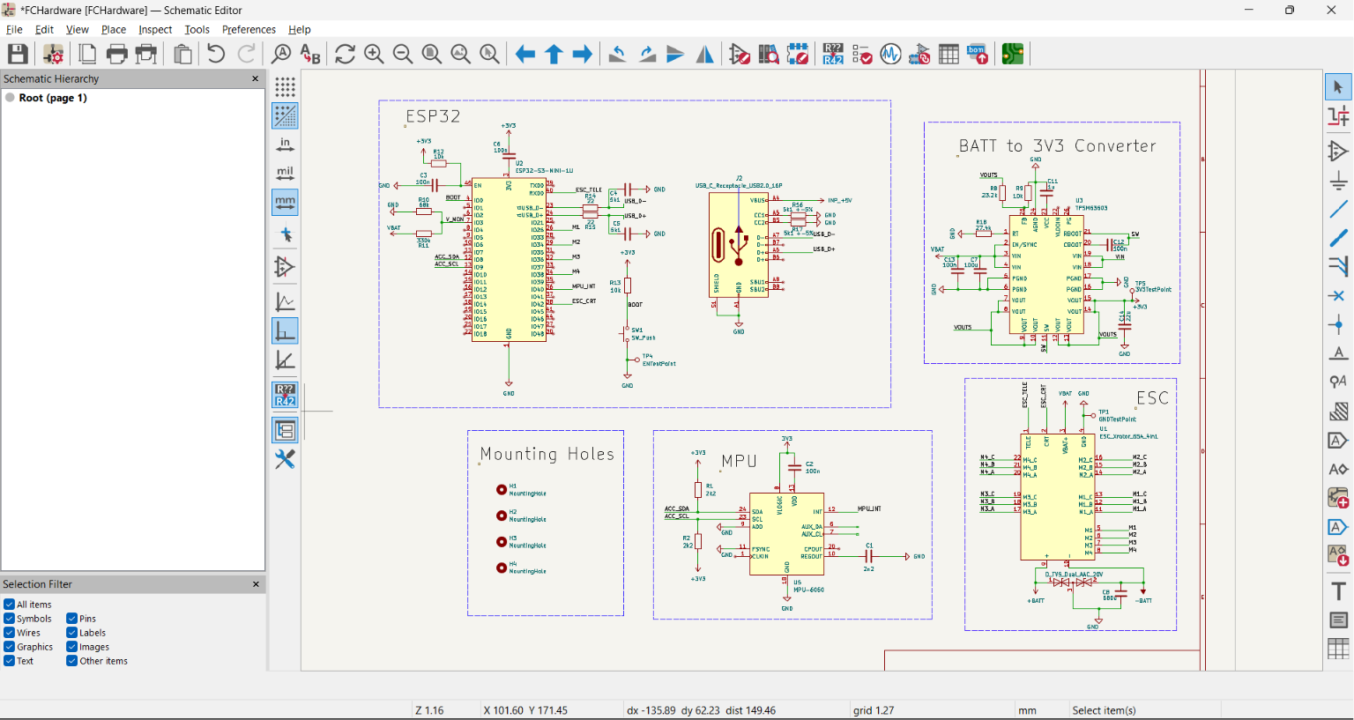
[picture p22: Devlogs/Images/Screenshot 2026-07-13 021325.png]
4S-6S Architecture Start


After my laptop crashed, I noticed the screen recorder froze for the last ~10 minutes and only recorded a still image. I added a screenshot of the completed work as proof of progress.

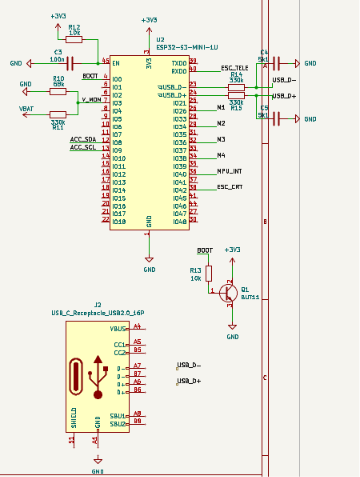
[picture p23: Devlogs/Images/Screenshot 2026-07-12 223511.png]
USB C


## TODO:
- Verify the TPSM63603 wiring against the TI reference schematic.
- Check all capacitor values and voltage ratings.
- Verify the feedback resistor values for a 3.3 V output.
- Add a capacitor on the battery voltage monitoring line (V_MON).
- Run ERC before starting PCB layout.
- Begin PCB component placement.
- Go touch the grass and finally sleep.

--------------------
created_at: "2026-07-13"
Lapse Links:
- [Lapse Schematics 10](https://lapse.hackclub.com/timelapse/1pxt6WZpChBw)
- [Lapse Schematics 11](https://lapse.hackclub.com/timelapse/10gVjKCt_ep9)
- [Flight Controller Footprints 1](https://lapse.hackclub.com/timelapse/hQegLY-AzRu6)
- [Flight Controller Footprints 2](https://lapse.hackclub.com/timelapse/EoTzfVyzHLk1)

### Day 6
Continued refining the flight controller schematic and completed the transition to support a **4S–6S LiPo** power input. I replaced the original 20 V TVS diode with a **Vishay SMBJ28A**, which has a 28 V reverse working voltage, making it suitable for a fully charged 6S LiPo (25.2 V) while still providing transient protection.

While reviewing the schematic, I discovered a short circuit by using KiCad's **Net Highlight** tool. Highlighting the **3.3 V** net also highlighted **GND**, immediately indicating a direct short. After tracing the connection, I found that the ESP32's 3.3 V decoupling capacitors had been wired incorrectly. Fixing the capacitor connections removed the short.

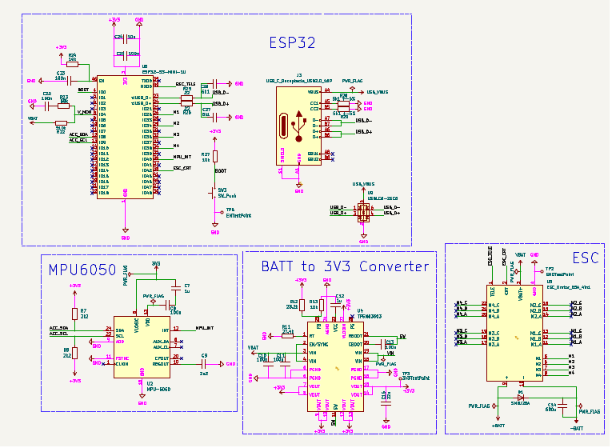
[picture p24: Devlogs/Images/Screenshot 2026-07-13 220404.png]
Shorted Schematics


With the power circuitry corrected, I finished updating the schematic for reliable 4S–6S operation and performed a full schematic review, cleaning up ERC issues along the way.

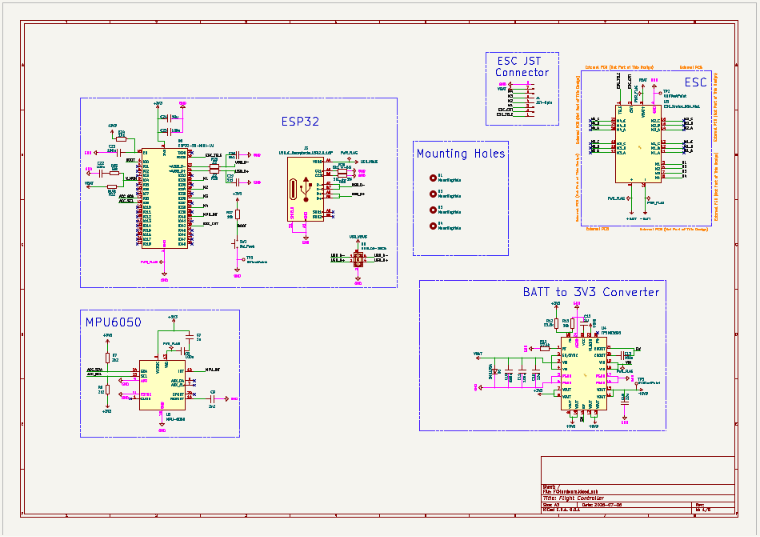
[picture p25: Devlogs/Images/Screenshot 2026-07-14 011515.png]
Fixed 4S-6S Schematics


The final result was reducing the ERC report from **more than 60 errors to zero**. Most of the remaining issues were caused by decorative net labels, intentionally unused pins, and missing ERC markers rather than actual electrical problems. After replacing decorative labels with graphical text, adding No Connect markers where appropriate, and fixing the genuine wiring mistakes, the schematic passed ERC without any errors.

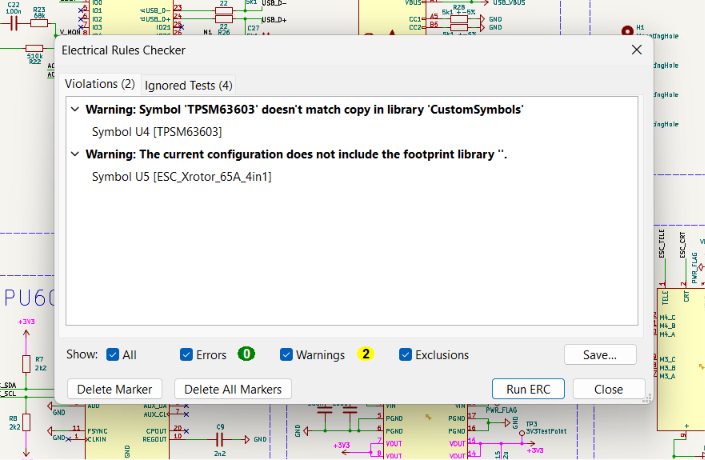
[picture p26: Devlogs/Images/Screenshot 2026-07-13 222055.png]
ERC Showing 0 Errors


--------------------
created_at: "2026-07-14"

Lapse Links:
- [Flight Controller Footprints 3](https://lapse.hackclub.com/timelapse/lF_Vx_5Nq1XL)
- [Flight Controller Components 1](https://lapse.hackclub.com/timelapse/Cr0G3cQVFeo1)

### Day 7
Moving on to Footprints.

Started assigning footprints to all components in the schematic. While selecting them, I also checked whether the chosen packages would actually be practical to solder by hand. For example, I verified that the 1210 package for the 630 V, 68 nF X7R MLCC (C10) should still be manageable for manual soldering.

I also created a few files that will continue to evolve throughout the project. They are not finished yet, but they need to be prepared before starting the actual PCB design if I want to build this flight controller in real life.

Bill of Material Exported from KiCad
Components References (manufacturer, part names, purchase links)

There were still many design decisions that required research before finalizing the PCB, including:

Choosing the correct footprint for the UJ20-C-H-G-SMT-2A-P16-TR USB-C connector and understanding which of its 16 pins are actually required for USB 2.0 operation.
Selecting appropriate test point sizes.
Deciding whether the external XRotor ESC should remain in the schematic without a footprint or be excluded from PCB generation.
Choosing suitable push buttons for the BOOT and RESET functions.
Verifying that the RESET circuit had not been forgotten and was wired correctly.

I spent quite a bit of time looking up components, comparing alternatives, and selecting footprints that match the actual parts.

I also used TI WEBENCH to generate and compare a custom implementation of the TPSM63603 buck converter and to better understand the recommended layout and surrounding components.

After going through the entire schematic, I assigned footprints to every component except the external ESC, which is not part of the flight controller PCB.

I also corrected several pin assignments and footprint mismatches that would have caused ERC errors later during the design process.

One thing I have learned is that designing the schematic itself is only part of the work. Researching components is surprisingly time-consuming. Every resistor, capacitor, connector, and integrated circuit has multiple possible variants, each with different voltage ratings, tolerances, packages, manufacturers, and availability. Learning the correct engineering terminology and understanding datasheets well enough to choose the appropriate parts has been one of the more challenging aspects of the project.

Fortunately, it looks like I should be able to purchase most of the required components from Mouser Finland, which would make ordering much simpler.

Another question that has started to interest me is whether designing and manufacturing a custom flight controller actually makes economic sense. After spending time designing the hardware, debugging it, ordering components, assembling the PCB, and testing everything, is there any real cost advantage left? Or is it simply cheaper to buy an already proven flight controller from one of the large Chinese manufacturers unless a very specific custom feature is needed?

Once I finish the ComponentsReferences.md file, I plan to add the price of every component and calculate the total cost of the flight controller. I'm genuinely curious to see what the final number will be and how it compares to commercially available flight controllers.

If you're reading this: Author wrote it sitting at the railway station with 12h of sleep in the past week. I'm kinda dedicated to this project and kinda wanna sleep. "To sleep or not to sleep?" - That is the question!

Fortunately, it looks like I should be able to purchase most of the required components from Mouser Finland, which will make ordering everything much simpler. However, finding actual components instead of just selecting values from a schematic turned out to be much more difficult than I expected. Every capacitor, resistor, connector, and protection device comes in dozens or even hundreds of variants with different package sizes, voltage ratings, tolerances, temperature characteristics, and manufacturers. Learning how to choose real parts that satisfy both the electrical requirements and are still practical to solder by hand has probably been one of the most time-consuming parts of the project so far. I documented the selected components in [Components References](../ComponentsReferences.md).

-------
created_at: "2026-07-17"

Lapse Links:
- [Flight Controller Schematics 12](https://lapse.hackclub.com/timelapse/qFTWT7Qf1Yv2)
- [Flight Controller Schematics 13](https://lapse.hackclub.com/timelapse/cIjbhHLziKkF)
- [Flight Controller Footprints 4](https://lapse.hackclub.com/timelapse/JtB1HHLpG3G7)

### Day 8
Betaflight It Is

Decided to drop the idea of writing custom firmware and instead target Betaflight for the first revision of the flight controller. This meant replacing the ESP32-S3 with the STM32F405RGT6, rewiring the MCU, and redesigning the project around hardware already supported by the Betaflight ecosystem.

Initially I considered the MPU6000 because of its popularity, but it is getting old and harder to source. Instead, I switched to the ICM-42688-P, which offers better performance while still being supported. I also found an evaluation board, so if anything goes wrong I can always inspect a working design or even salvage the chip if necessary.

Moved all custom libraries into the project directory to make the repository self-contained. Reworked the STM32 power circuitry by connecting all required digital and analog supply pins according to the datasheet and referenced official development board schematics to verify the implementation.

Simplified the boot and reset circuits to save PCB space. Instead of dedicated buttons, both BOOT0 and NRST are exposed as test pads. BOOT0 is held low by default through a pull-down resistor so Betaflight boots normally, and can be pulled high to 3.3 V only when entering the STM32 bootloader for firmware flashing.

Although the primary target is Betaflight, the hardware should also be capable of running ArduPilot with some limitations, so I tried to keep the design compatible with both ecosystems.

The IMU interface was changed from I²C to SPI for better performance and lower latency, which is the preferred configuration for modern flight controllers.

The power architecture was expanded to include both 5 V and 3.3 V rails. The TPSM63603 now generates the 5 V supply for peripherals such as the ExpressLRS receiver, with room for a future FPV camera and LiDAR module, while an AP2112K-3.3 LDO provides a clean 3.3 V rail for the MCU and sensors. I also added a JST connector for the receiver.

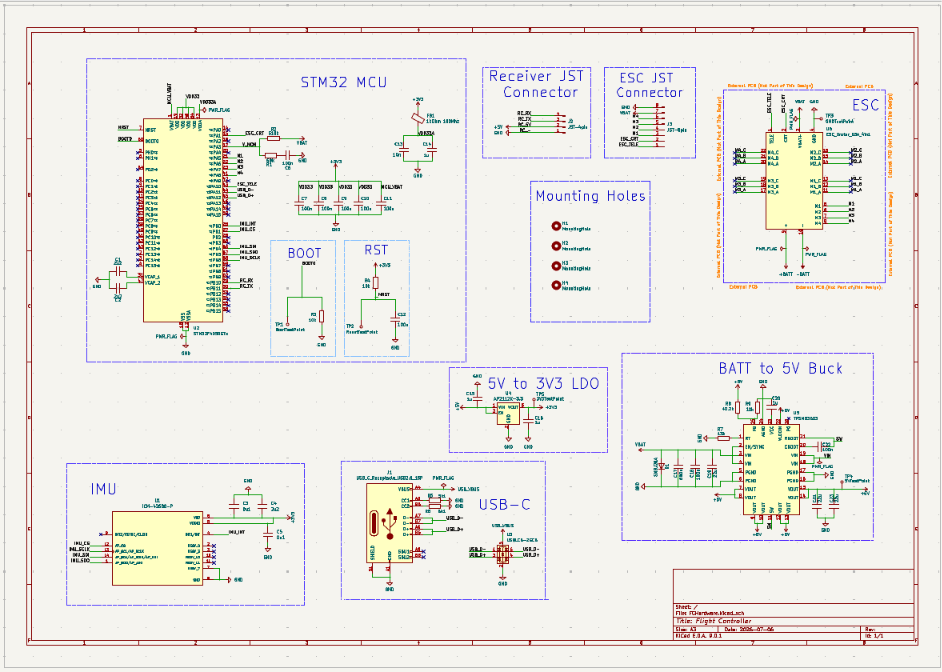
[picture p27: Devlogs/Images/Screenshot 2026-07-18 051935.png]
New Schematics


Spent quite some time chasing electrical rule check issues—at one point there were 41 ERC errors, but eventually got the count down to zero.

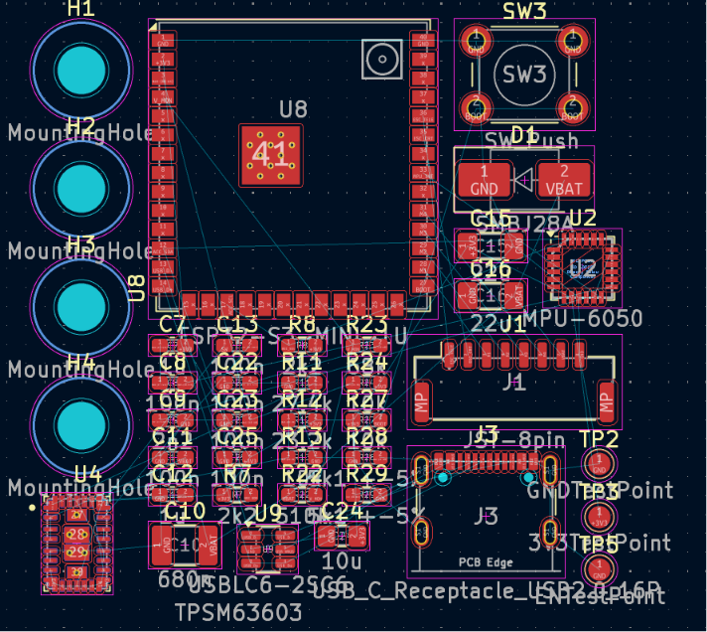
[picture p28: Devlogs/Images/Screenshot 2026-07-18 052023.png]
PCB view unwired


Updated the Bill of Materials with production-ready components and, after breaking most of the footprint assignments during the redesign, rebuilt all footprints from scratch. It was honestly faster than trying to fix the old assignments one by one.

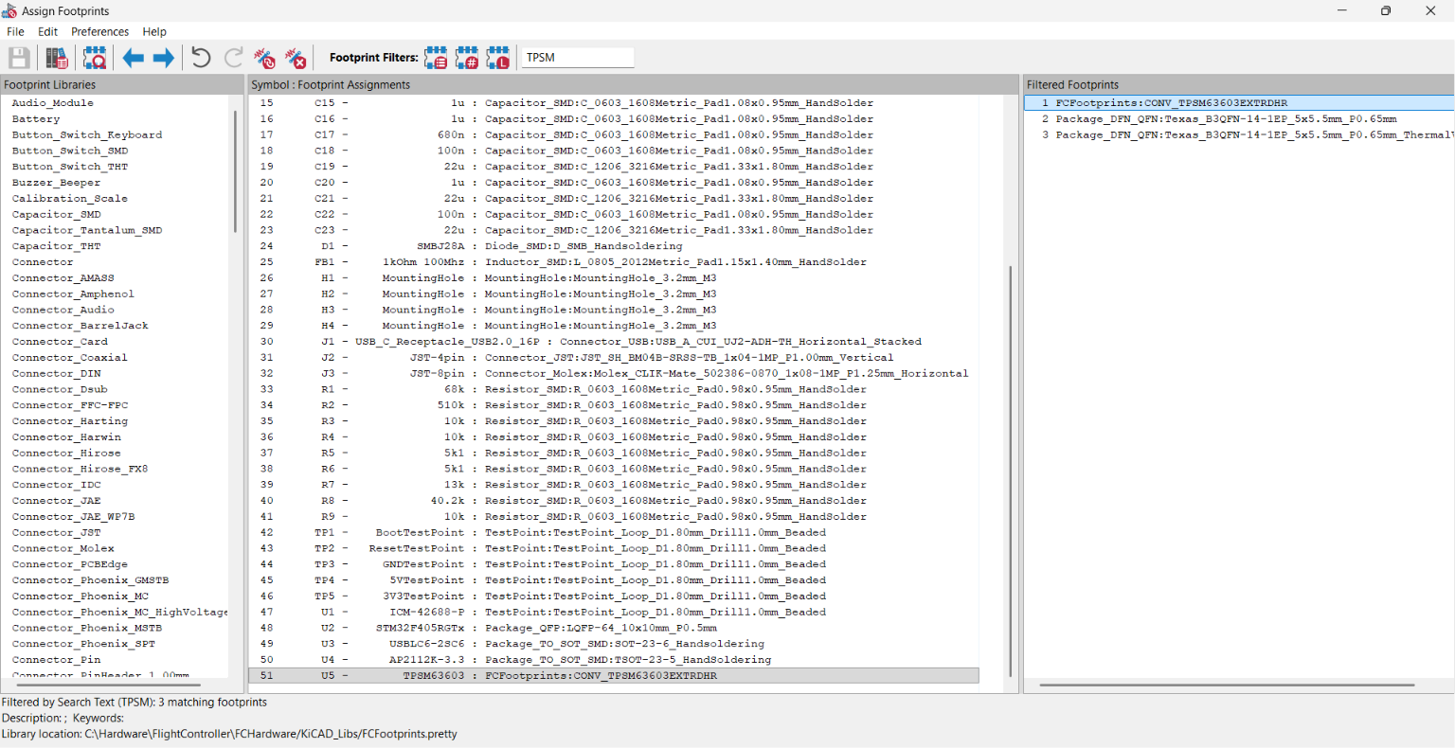
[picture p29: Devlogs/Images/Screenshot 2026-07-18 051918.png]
Footprints

 
 Btw, I really like this journal entry. Rereading it makes me understand that this project has taught me more than I expected. 

 -------
### Day 9-10
created_at: "2026-07-18/19"

Lapse Links:
- [Flight Controller Schematics 13](https://lapse.hackclub.com/timelapse/cIjbhHLziKkF)
- [Flight Controller Footprints 4](https://lapse.hackclub.com/timelapse/JtB1HHLpG3G7)
- [Flight Controller Fixing Errors 1](https://lapse.hackclub.com/timelapse/O3XZnc101T1P)
- [Flight Controller Routing 0](https://lapse.hackclub.com/timelapse/yKk5Ec0wwg1U)
- [Flight Controller Routing 1](https://lapse.hackclub.com/timelapse/HK290xkNnn8u)

Started by switching the STM32 footprint and adding proper 3D models. Also aligned the USB-C symbol with its footprint because it was rotated differently. Fixed yesterday's mistake with the IMU test point footprint and noticed that the TPSM63603 footprint was missing three pins... somehow.

```text
Warning: No net found for component J2 pad MP (no pin MP in symbol).
Warning: No net found for component J3 pad MP (no pin MP in symbol).
```

Spent quite a while hunting down footprint/symbol mismatches. In the end, every footprint and symbol matched properly and the import errors disappeared. It was surprisingly satisfying seeing the schematic finally clean up.

Final schematic for now.

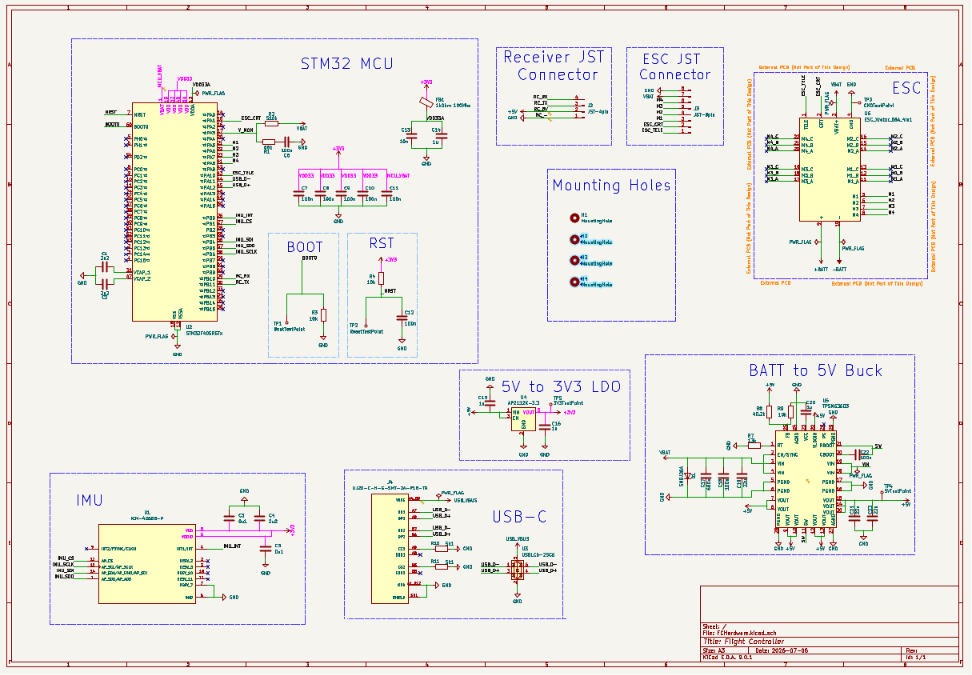
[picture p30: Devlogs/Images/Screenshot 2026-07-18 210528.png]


Started component placement. I wanted some reference from real flight controllers to make the layout feel familiar. The goal was to keep the FC the same size as the ESC (30.5 × 30.5 mm mounting pattern, 39 × 39 mm PCB with 3.2 mm corner fillets).

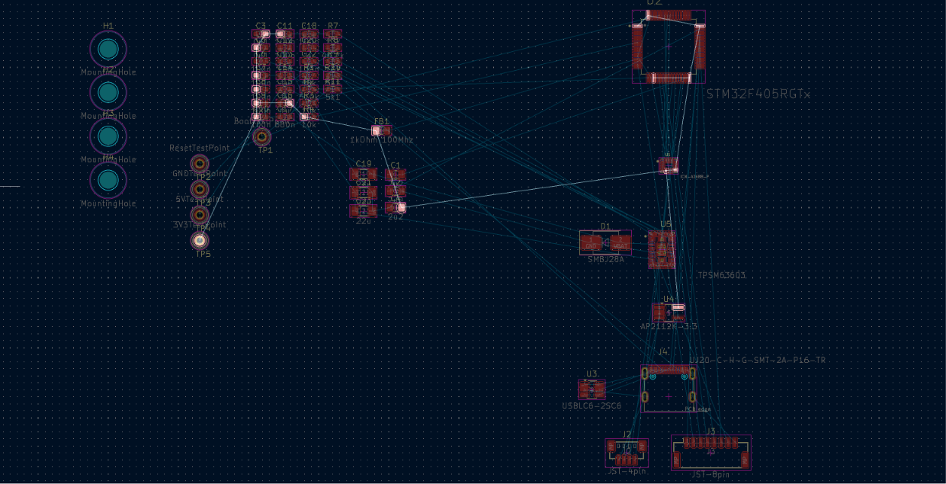
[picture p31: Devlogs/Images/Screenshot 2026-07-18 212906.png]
Placing components

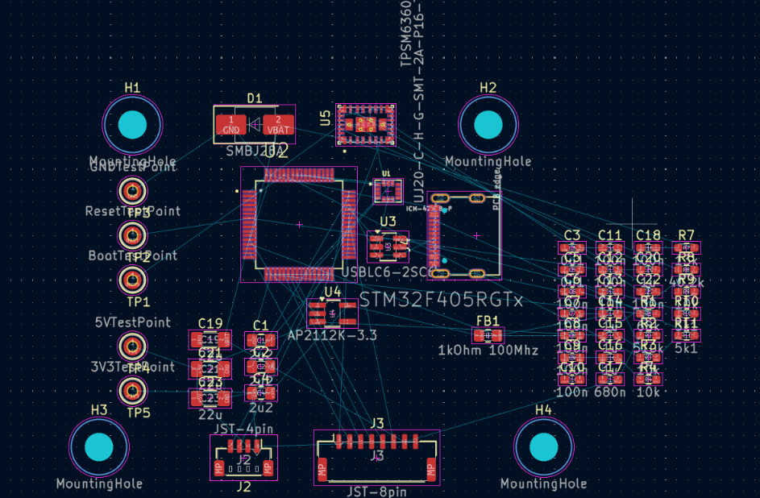
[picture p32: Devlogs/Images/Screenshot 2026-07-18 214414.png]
Placement idea 1

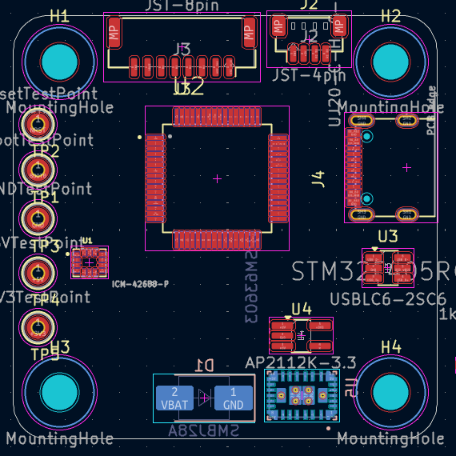
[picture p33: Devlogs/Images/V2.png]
Main component placement


Added what felt like an endless number of capacitors, resistors and the ferrite bead. Also corrected the orientation of the ICM-42688-P according to the datasheet before getting too far.

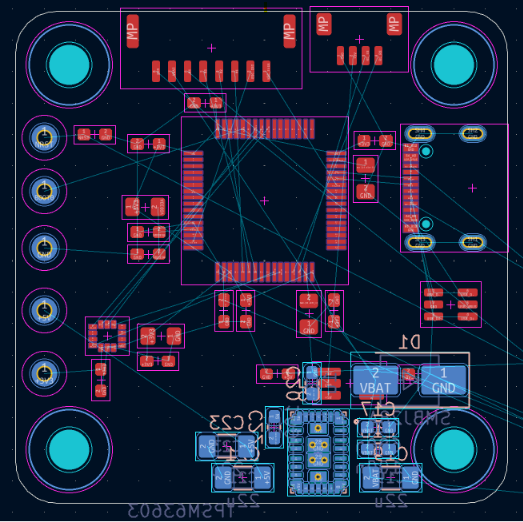
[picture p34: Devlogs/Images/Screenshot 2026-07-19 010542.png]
Placed capacitors and ferrite bead

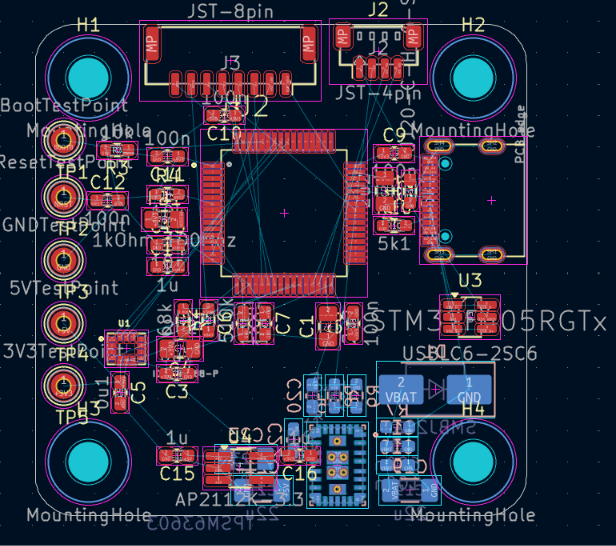
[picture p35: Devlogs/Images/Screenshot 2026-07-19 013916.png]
With resistors


Before routing, I configured the board design rules.

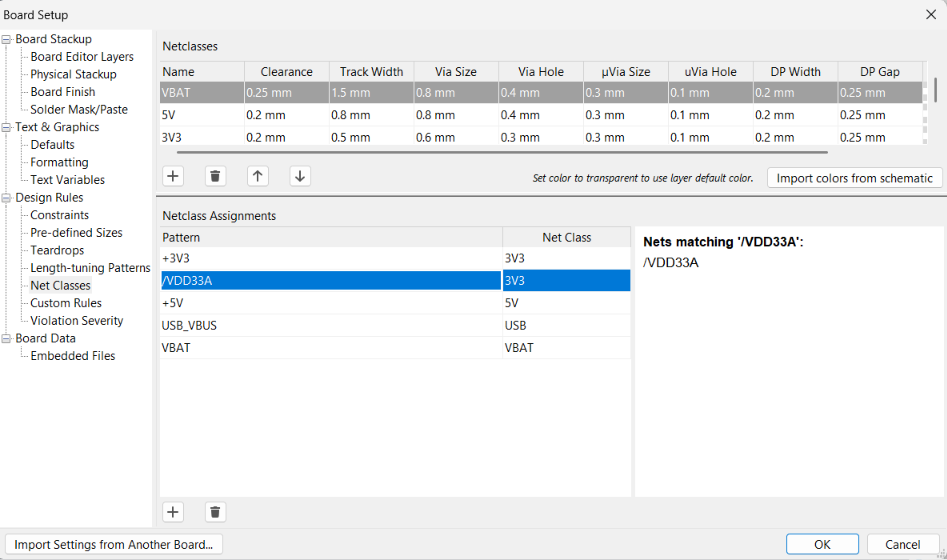
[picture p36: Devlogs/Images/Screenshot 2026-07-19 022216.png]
Design rules


Then came the TPSM63603...

Routing the buck converter was an absolute nightmare. It felt like every pin wanted to go in the opposite direction. Halfway through I realised VIN wasn't actually connected because I had left it as an empty net label. At this point I was convinced whoever designed this package was personally trying to make PCB routing harder.

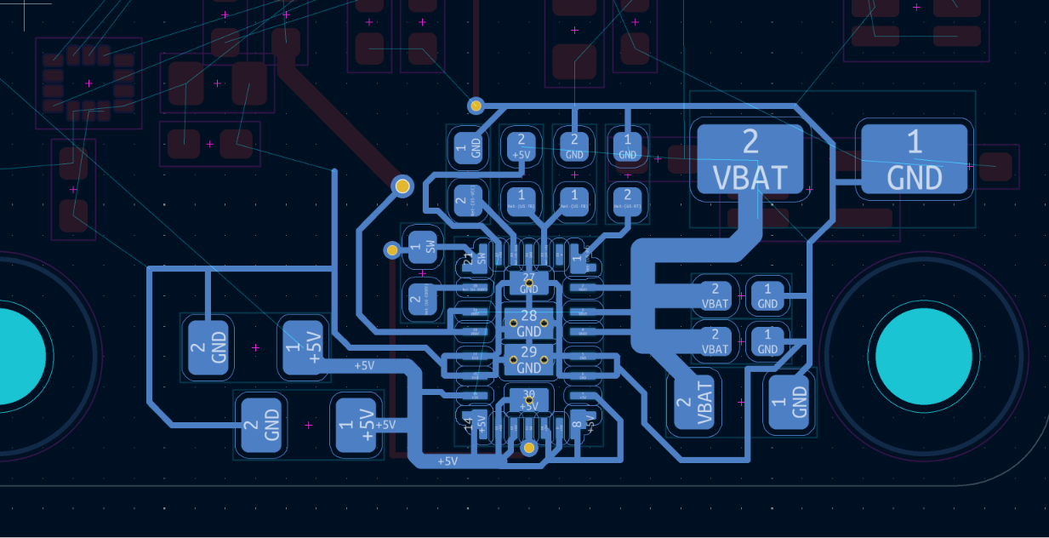
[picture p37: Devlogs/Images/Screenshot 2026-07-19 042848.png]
Buck converter routing nightmare


The STM32 wasn't much kinder. Routed a good portion of it but there is still plenty left. Need to double-check the serial UART pin assignments before I commit to the routing.

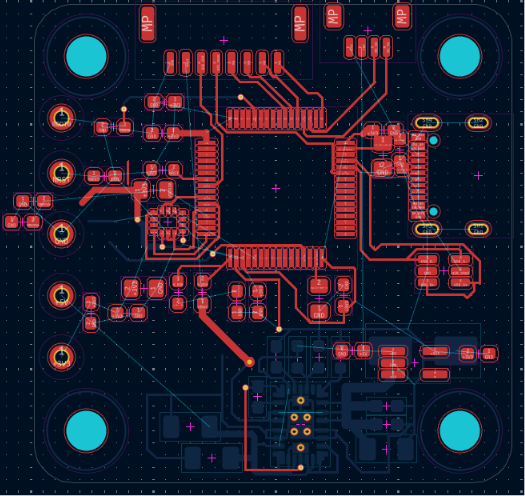
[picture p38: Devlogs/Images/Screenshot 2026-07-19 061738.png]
STM32 routing progress


---------------
### Day 11 + 12
created_at: "2026-07-20/21"

Lapse Links:
- [Flight Controller Routing 2](https://lapse.hackclub.com/timelapse/HWvUumr3cuOM)
- [Flight Controller Routing 3](https://lapse.hackclub.com/timelapse/GjfclvQMqYpr)
- [Flight Controller Routing 4](https://lapse.hackclub.com/timelapse/cDtOHCTtI151)
- [Flight Controller Routing 5](https://lapse.hackclub.com/timelapse/sghr0FeVSwDz)
- [Flight Controller CAD Design 1](https://lapse.hackclub.com/timelapse/KtIpimI4lsoy)
- [Flight Controller CAD Design 2](https://lapse.hackclub.com/timelapse/a1JzYd-nAppO)
Finished almost all of the routing. The board is finally starting to look like an actual flight controller instead of a spiderweb of airwires. I still wanted to see if I could move a few resistors and capacitors to the back side to reduce congestion around the MCU.

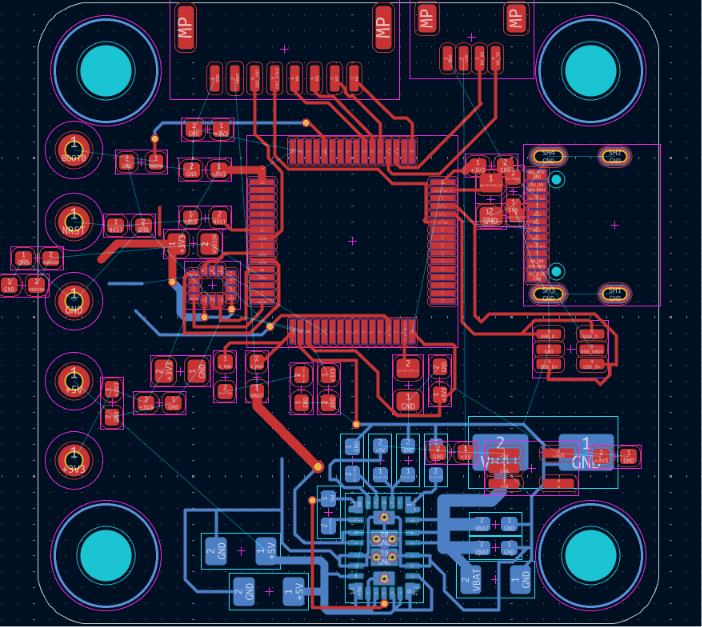
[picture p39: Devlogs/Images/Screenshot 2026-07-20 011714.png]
Routing progress


USB-C ended up being much harder than expected. Since the differential pairs should have the same electrical length, using vias meant each line in the pair also needed the same number of vias. That made routing around the connector surprisingly frustrating.

With everything except ground completed, it was finally time for copper pours.

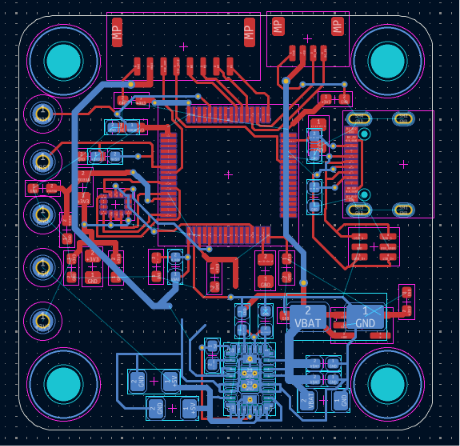
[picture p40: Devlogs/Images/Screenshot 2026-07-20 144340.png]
Without GND

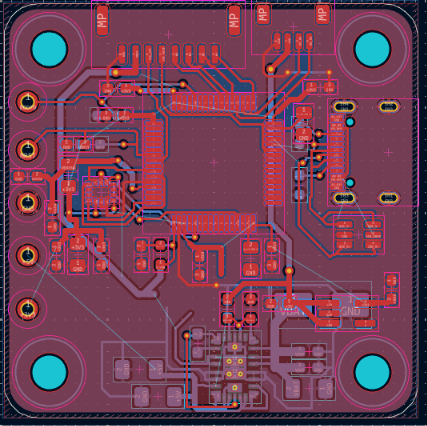
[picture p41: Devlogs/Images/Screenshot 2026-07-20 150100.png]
GND copper zones


...and then I realised I had completely forgotten to route some of the power rails.

After that came cleanup. Removing unnecessary 90° corners, simplifying traces, reducing the number of vias where possible and generally making the routing look cleaner.

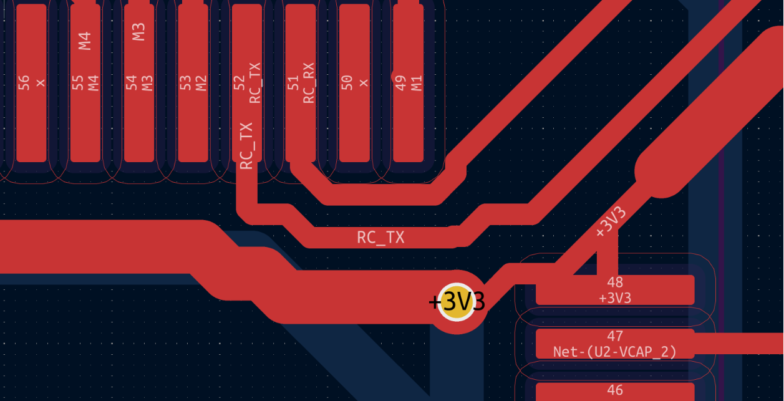
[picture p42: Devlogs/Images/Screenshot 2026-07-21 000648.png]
Before cleanup

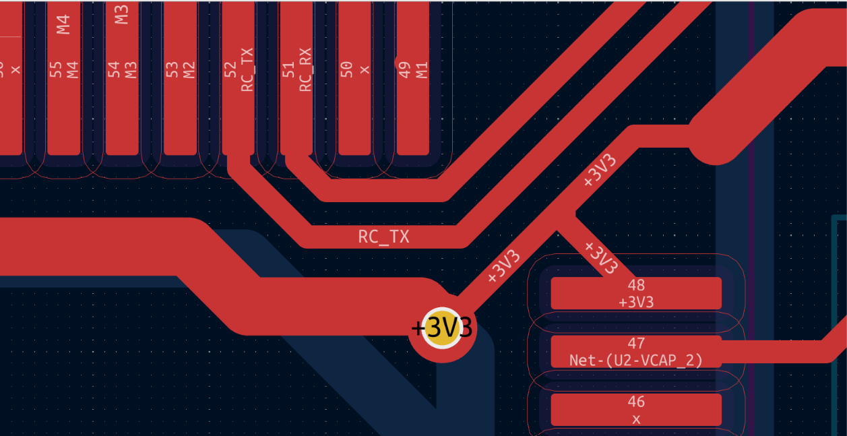
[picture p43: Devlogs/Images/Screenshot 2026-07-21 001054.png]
After cleanup

Back looks much cleaner
Front cleanup
Final front cleanup

Then came the Design Rule Checker...

Started with around **56 errors** and **256 warnings**.

One particularly embarrassing mistake: I had connected the USB D+ and D− lines from the connector to the ESD diode... and then back to the USB connector instead of the STM32.

Also learned (the hard way) that the USBLC6-2SC6 goes **in parallel**, not in series.

And then there was the TPSM63603 again.

Whoever placed pin 22 in the middle of the package with no regard for routing... I have questions. Routing idea for that thing probably violates the Geneva Convention.

Added stitching vias, fixed the remaining issues, created a few justified DRC exceptions, and finally reached **0 unconnected items**.

Time for the fun part.

Added all the 3D models and spent way too long just spinning the PCB around.

2D PCB
3D front
3D back
Schematics

Finally imported the ESC into Fusion 360 and assembled the complete FC + ESC stack with screws, spacers and connectors.

CAD FC + ESC
CAD FC + ESC

I honestly couldn't stop looking at it.

A few days ago this was just a schematic with hundreds of ratsnest lines. Now it's an actual flight controller that could be manufactured.

It took far longer than I expected. There were moments where I questioned almost every routing decision, fought DRC, ERC, USB-C, the buck converter and pretty much every footprint at least once.

But it's done.

**0 ERC errors.**
**0 DRC errors.**

It feels unreal seeing something that started as an idea become a complete PCB.

---

### Ideas for V2

- Better ESC integration.
- Cleaner routing around the buck converter.
- Add LiDAR connector/support.
- Improve mechanical integration with the frame.

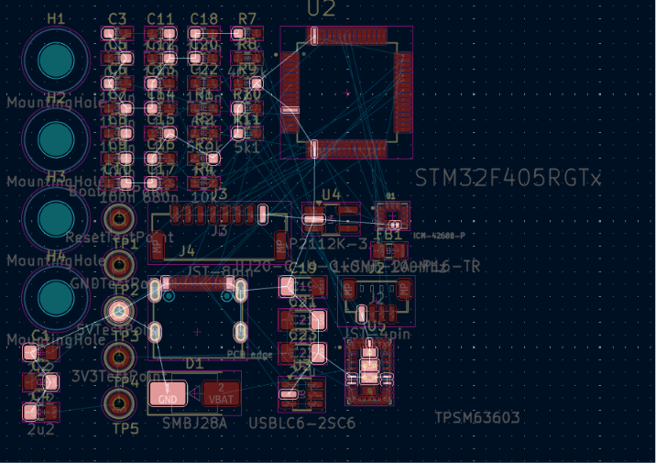
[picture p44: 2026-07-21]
Devlogs/Images/Screenshot 2026-07-18 210209.png

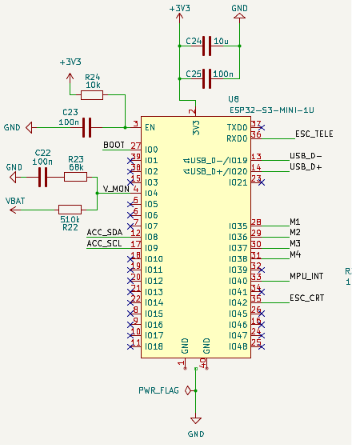
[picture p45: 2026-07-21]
Devlogs/Images/Screenshot 2026-07-14 084945.png

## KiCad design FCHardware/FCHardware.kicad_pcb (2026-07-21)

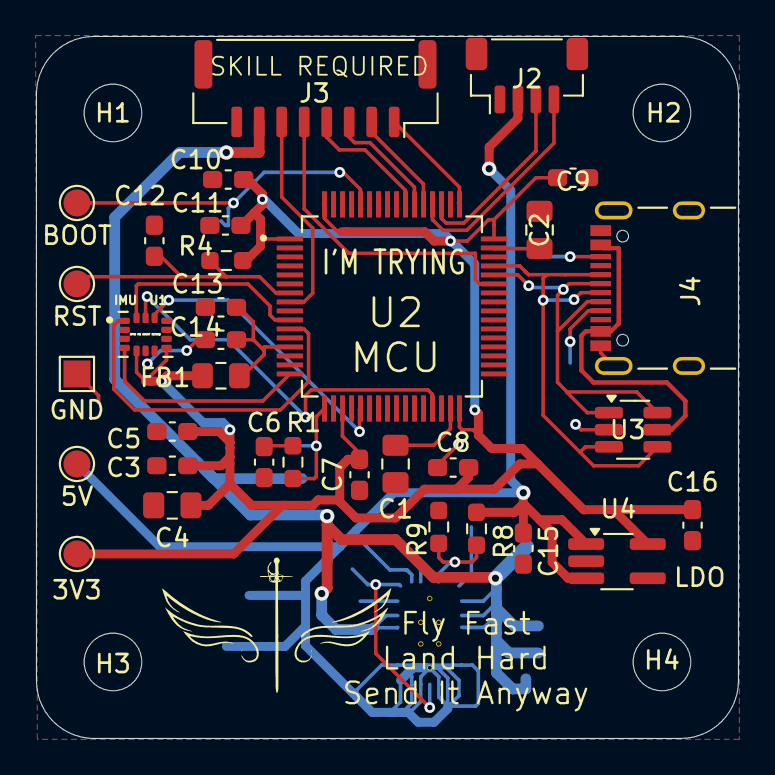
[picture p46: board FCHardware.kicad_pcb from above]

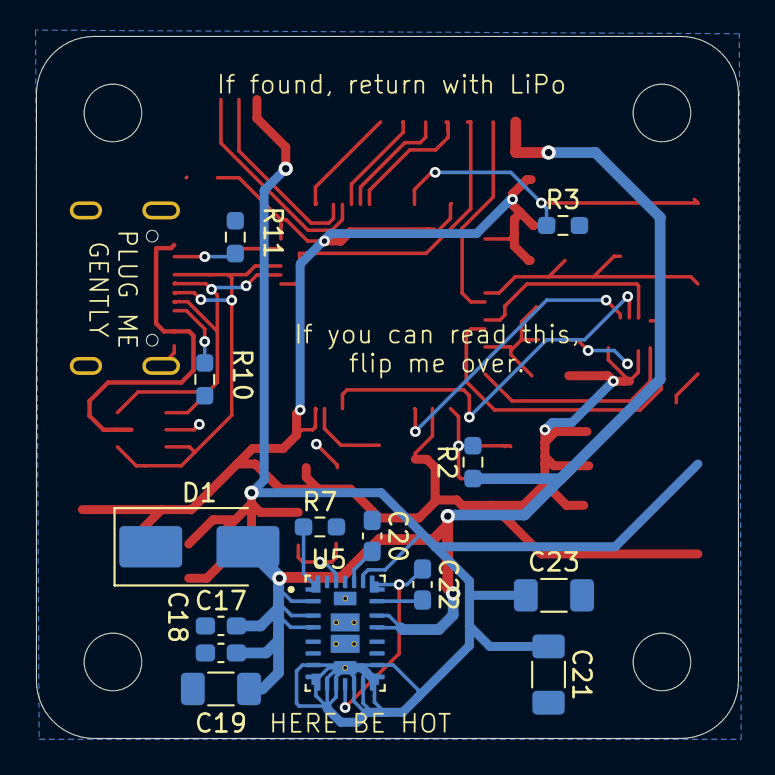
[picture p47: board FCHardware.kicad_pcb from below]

Board: 2 copper layers, 39.0 x 39.0 mm, 51 parts (14 on the bottom side), 34 nets.

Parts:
3V3: 3V3TestPoint; TestPoint_Pad_D1.5mm
5V: 5VTestPoint; TestPoint_Pad_D1.5mm
BOOT: BootTestPoint; TestPoint_Pad_D1.5mm
C1, C2, C4: 2u2; C_0805_2012Metric_Pad1.18x1.45mm_HandSolder
C3, C5: 0u1; C_0603_1608Metric_Pad1.08x0.95mm_HandSolder
C6, C7, C8, C9, C10, C11, C12, C18, C22: 100n; C_0603_1608Metric_Pad1.08x0.95mm_HandSolder
C13: 10n; C_0603_1608Metric_Pad1.08x0.95mm_HandSolder
C14, C15, C16, C20: 1u; C_0603_1608Metric_Pad1.08x0.95mm_HandSolder
C17: 680n; C_0603_1608Metric_Pad1.08x0.95mm_HandSolder
C19, C21, C23: 22u; C_1206_3216Metric_Pad1.33x1.80mm_HandSolder
D1: SMBJ28A; D_SMB_Handsoldering
FB1: 1kOhm 100Mhz; L_0805_2012Metric_Pad1.15x1.40mm_HandSolder
GND: GNDTestPoint; TestPoint_Pad_1.5x1.5mm
H1, H2, H3, H4: MountingHole; MountingHole_3.2mm_M3
J2: JST-4pin; JST_SH_BM04B-SRSS-TB_1x04-1MP_P1.00mm_Vertical
J3: JST-8pin; Molex_CLIK-Mate_502386-0870_1x08-1MP_P1.25mm_Horizontal
J4: UJ20-C-H-G-SMT-2A-P16-TR; SAMESKY_UJ20-C-H-G-SMT-2A-P16-TR
R1: 68k; R_0603_1608Metric_Pad0.98x0.95mm_HandSolder
R2: 510k; R_0603_1608Metric_Pad0.98x0.95mm_HandSolder
R3, R4, R9: 10k; R_0603_1608Metric_Pad0.98x0.95mm_HandSolder
R7: 13k; R_0603_1608Metric_Pad0.98x0.95mm_HandSolder
R8: 40.2k; R_0603_1608Metric_Pad0.98x0.95mm_HandSolder
R10, R11: 5k1; R_0603_1608Metric_Pad0.98x0.95mm_HandSolder
RST: ResetTestPoint; TestPoint_Pad_D1.5mm
U1: ICM-42688-P; PQFN50P300X250X97-14N
U2: STM32F405RGTx; QFP50P1200X1200X160-64N
U3: USBLC6-2SC6; SOT-23-6_Handsoldering
U4: AP2112K-3.3; TSOT-23-5_HandSoldering
U5: TPSM63603; CONV_TPSM63603EXTRDHR

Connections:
+3V3: 3V3.1, C3.2, C4.2, C5.1, C7.1, C8.1, C9.1, C10.1, C11.1, C16.2, FB1.1, R4.1, U1.5 (VDDIO), U1.8 (VDD), U2.1 (VBAT), U2.19 (VDD), U2.32 (VDD), U2.48 (VDD), U2.64 (VDD), U4.5 (VOUT)
+5V: 5V.1, C15.1, C21.1, C23.1, J2.2, R8.2, U4.1 (VIN), U4.3 (EN), U5.7 (VOUT), U5.8 (VOUT), U5.9 (VOUT), U5.10 (VOUT), U5.12 (VOUT), U5.13 (VOUT), U5.14 (VOUT), U5.15 (VOUT), U5.22 (VLDOIN), U5.30 (VOUT)
/BOOT0: BOOT.1, R3.1, U2.60 (BOOT0)
/ESC_CRT: J3.6, U2.8 (PC0)
/ESC_TELE: J3.5, U2.43 (PA10)
/IMU_CS: U1.12 (AP_CS), U2.21 (PA5)
/IMU_INT: U1.4 (INT1/INT), U2.16 (PA2)
/IMU_SCLK: U1.13 (AP_SCL/AP_SCLK), U2.29 (PB10)
/IMU_SDI: U1.14 (AP_SDA/AP_SDIO/AP_SDI), U2.10 (PC2)
/IMU_SDO: U1.1 (AP_SDO/AP_AD0), U2.11 (PC3)
/M1: J3.1, U2.49 (PA14)
/M2: J3.2, U2.53 (PC12)
/M3: J3.3, U2.54 (PD2)
/M4: J3.4, U2.55 (PB3)
/NRST: C12.1, R4.2, RST.1, U2.7 (NRST)
/RC_RX: J2.3, U2.51 (PC10)
/RC_TX: J2.4, U2.52 (PC11)
/SW: C22.1, U5.11 (SW), U5.21 (RBOOT)
/USB_D+: J4.A6 (DP1), J4.B6 (DP2), U2.45 (PA12), U3.3 (I/O2), U3.4 (I/O2)
/USB_D-: J4.A7 (DN1), J4.B7 (DN2), U2.44 (PA11), U3.1 (I/O1), U3.6 (I/O1)
/VDD33A: C13.2, C14.2, FB1.2, U2.13 (VDDA)
/V_MON: R1.1, R2.2, U2.17 (PA3)
GND: C1.1, C2.2, C3.1, C4.1, C5.2, C6.1, C7.2, C8.2, C9.2, C10.2, C11.2, C12.2, C13.1, C14.1, C15.2, C16.1, C17.1, C18.1, C19.1, C20.1, C21.2, C23.2, D1.1 (K), GND.1, J2.1, J3.8, J4.A1_B12 (GND), J4.B1_A12 (GND), J4.SH1 (SHIELD), J4.SH2 (SHIELD), J4.SH3 (SHIELD), J4.SH4 (SHIELD), R3.2, R7.1, R9.2, R10.1, R11.1, U1.6 (GND), U1.7 (RESV_7), U2.12 (VSSA), U2.18 (VSS), U2.63 (VSS), U3.2 (GND), U4.2 (GND), U5.5 (PGND), U5.6 (PGND), U5.16 (PGND), U5.17 (PGND), U5.24 (AGND), U5.27 (AGND), U5.28 (PGND), U5.29 (PGND)
unnamed: C6.2, R1.2
unnamed: J4.A5 (CC1), R10.2
unnamed: J4.B5 (CC2), R11.2
unnamed: C1.2, U2.31 (VCAP_1)
unnamed: C2.1, U2.47 (VCAP_2)
unnamed: C22.2, U5.20 (CBOOT)
unnamed: R8.1, R9.1, U5.25 (FB)
unnamed: R7.2, U5.1 (RT)
unnamed: C20.2, U5.23 (VCC)
USB_VBUS: J4.A4_B9 (VBUS), J4.B4_A9 (VBUS), U3.5 (VBUS)
VBAT: C17.2, C18.2, C19.2, D1.2 (A), J3.7, R2.1, U5.2 (EN/SYNC), U5.3 (VIN), U5.4 (VIN), U5.18 (VIN), U5.19 (VIN)

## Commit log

2026-07-06 Added basic schematics components
    [FCHardware.kicad_pcb, FCHardware.kicad_sch]
2026-07-06 Added Power and Motor Management, Accelerator
    [FCHardware.kicad_sch]
2026-07-07 Changed main controller to Feather 32 and updated schematics accordingly
    [FCHardware.kicad_sch]
2026-07-07 Updated configuration to 2S LiPo battery
    [FCHardware.kicad_sch]
2026-07-07 Fixed TPS62125DSG power inputs/outputs
    [FCHardware.kicad_sch]
2026-07-10 Switched from TPS62125 to TPS629203
    [FCHardware.kicad_sch]
2026-07-10 Added Xrotor 65A as ESC instead of H-bridges
    [FCHardware.kicad_sch]
2026-07-10 Chaged connectors for brushless motors
    [FCHardware.kicad_sch]
2026-07-10 Fixed mismatch in ESC piout, removed connectors, wired ESC
    [FCHardware.kicad_sch]
2026-07-10 Added voltage monitor
    [FCHardware.kicad_sch]
2026-07-11 Updated documentation
    [FCHardware.kicad_sch]
2026-07-12 Switched to ESP32-S3-MINI-1U
    [FCHardware.kicad_sch]
2026-07-12 Final fixes before updating to 6S
    [FCHardware.kicad_sch]
2026-07-12 Added TPSM63603 and wired it starting the transition towards the 4S - 6S architecture
    [FCHardware.kicad_sch]
2026-07-13 Replaced wrong diodes, added smoothening capacitorsr
    [FCHardware.kicad_sch]
2026-07-13 Passed ERC, fixed shorts
    [Converter.kicad_sch, ESC.kicad_sch, FCHardware.kicad_sch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]
2026-07-14 Assigned all the footprints
    [FCHardware.csv, FCHardware.kicad_sch]
2026-07-14 Imported footprints into the PCB view. Removed ESC footprint
    [FCHardware.kicad_pcb, FCHardware.kicad_sch]
2026-07-14 Added footprints journal
2026-07-14 Added actual references to capacitors and resistors
    [FCHardware.kicad_sch]
2026-07-17 Switched to STM mcu and ICM-42688 imu
    [FCHardware.kicad_sch]
2026-07-17 Added correct power management for STM32
    [FCHardware.kicad_sch]
2026-07-17 Fixed RST and BOOT sequences, wired STM32
    [FCHardware.kicad_sch]
2026-07-18 Added reciever, separated 3v3 and 5v rails
    [FCHardware.kicad_sch]
2026-07-18 Fixed ERC errors
    [FCHardware.kicad_sch]
2026-07-18 Updated BoM
    [FCHardware.kicad_sch]
2026-07-18 Added journal entry
    [ComponentsReferences.csv, FCHardware.kicad_sch]
2026-07-18 Fixed TPSM63603's symbol error
    [FCHardware.kicad_sch]
2026-07-18 Fixed symbols/footprints mismatch issues
    [FCHardware.kicad_sch]
2026-07-18 Created basic component placement
    [FCHardware.kicad_pcb]
2026-07-18 Placed the capacitors
    [FCHardware.kicad_pcb]
2026-07-18 Provisionally placed resistors
    [FCHardware.kicad_pcb]
2026-07-19 Fixed floating VIN in the schematics
    [FCHardware.kicad_sch]
2026-07-19 Provisional routing of TPSM63603
    [FCHardware.kicad_pcb]
2026-07-19 Swiched schematics for easier routing, provisional routing of STM32
    [FCHardware.kicad_pcb, FCHardware.kicad_sch]
2026-07-19 Routed MCU's Capacitors and Resistors Inputs
    [FCHardware.kicad_pcb]
2026-07-19 Wired the USB C
    [FCHardware.kicad_pcb]
2026-07-20 Fixed USB C routing
    [FCHardware.kicad_pcb]
2026-07-20 Routed VBAT 5V 3V3
    [FCHardware.kicad_pcb]
2026-07-20 Routed VDD33A and finished VDD33
    [FCHardware.kicad_pcb]
2026-07-20 Cleaned up the back routing
    [FCHardware.kicad_pcb]
2026-07-20 Cleaned up the front routing
    [FCHardware.kicad_pcb]
2026-07-20 Fixed DRC errors
    [FCHardware.kicad_pcb]
2026-07-21 Added 3D models
    [FCHardware.kicad_pcb]
2026-07-21 Added silkscreen components naming
    [FCHardware.kicad_pcb]
2026-07-21 Added Easter Eggs, fixed test points
    [FCHardware.kicad_pcb, FCHardware.kicad_sch]
2026-07-21 Add Fusion 360 CAD models with ESC
    [13mm.stl, CHC M3 L8.step, FC_ESC_Assembly.3mf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]
2026-07-21 Finilized the ReadME
    [ReferencesBoM.csv]
2026-07-21 Added missing media and libraries
    [ICM-42688-P.step, JST_SH_SM08B-SRSS-TB_1x08-1MP_P1.00mm_Horizontal.step, PRT-14417--3DModel-STEP-1.STEP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]
